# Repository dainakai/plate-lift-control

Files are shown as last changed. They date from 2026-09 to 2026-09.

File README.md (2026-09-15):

# plate-lift-control

Pololu Tic T825で校正用ガラスプレートを上げ下げします。
設定済みの68 mmストロークの装置向けです。

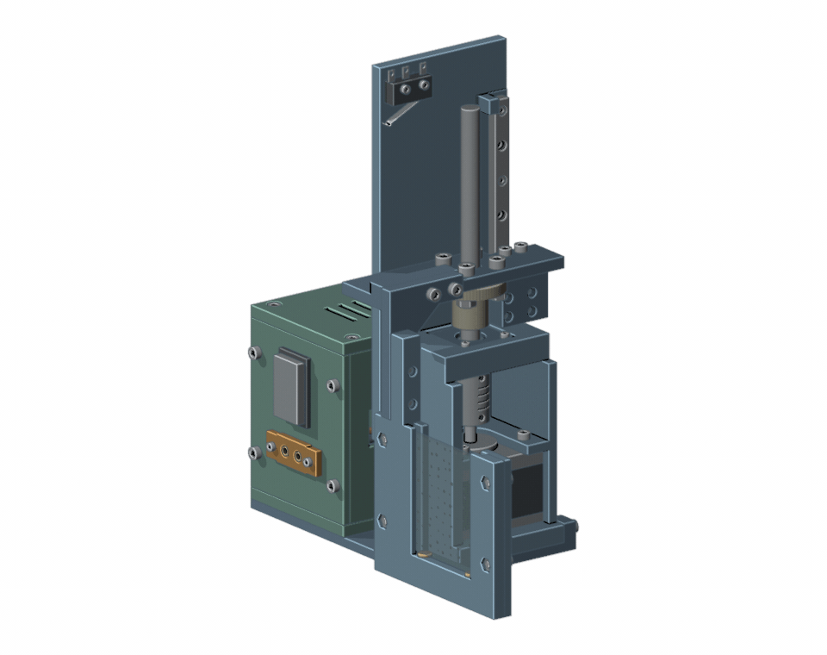
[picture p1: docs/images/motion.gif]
ガラスプレートが68 mm上下する3Dアセンブリの動作イメージ


購入部品を含む3Dモデルの動作イメージです（実機の撮影映像ではありません）。

**[組立・取扱説明書（PDF）](docs/assembly-manual.pdf)** · [購入部材一覧](hardware/bom.md) · **[印刷用STL一式（ZIP）](hardware/print-parts.zip)**

## クイックスタート

### 1. Ticソフトとuvを入れる

すでに入っているものはスキップしてください。

**Mac**

[Pololu公式のTic Software for macOS](https://www.pololu.com/docs/0J71/3.3)をインストールします。
続いてターミナルでuvを入れます。

```bash
curl -LsSf https://astral.sh/uv/install.sh | sh
```

**Windows**

[Pololu公式のTic Software and Drivers for Windows](https://www.pololu.com/docs/0J71/3.1)をインストールします。
続いてPowerShellでuvを入れます。

```powershell
winget install --id=astral-sh.uv -e
```

`winget` がない場合の方法は [uv公式のインストール手順](https://docs.astral.sh/uv/getting-started/installation/)にあります。
インストール後はターミナルまたはPowerShellを開き直してください。

### 2. ダウンロードして準備する

[ZIPをダウンロード](https://github.com/dainakai/plate-lift-control/archive/refs/heads/main.zip)して展開し、`plate-lift-control-main` フォルダを「ダウンロード」に置きます。

Mac：

```bash
cd ~/Downloads/plate-lift-control-main
uv sync
```

Windows：

```powershell
cd "$env:USERPROFILE\Downloads\plate-lift-control-main"
uv sync
```

Pythonとライブラリはuvが準備します。初回はインターネット接続が必要です。

### 3. 上げる／下げる

装置をパソコンへUSB接続し、モーター用のDC電源を接続します。
**DC電源は24 V以下に設定してください。直流安定化電源の最大電圧が21.2 VでもOKです。**
Tic Control Centerが起動中なら閉じてください（[Windowsでは同時にUSB接続できません](https://www.pololu.com/docs/0J71/4.4)）。
以下はMacとWindowsで共通です。必要なほうを実行します。

上げる：

```text
uv run platectl up
```

下げる：

```text
uv run platectl down
```

**普段の操作で、Tic Control Centerを開いてApply settingsを行う必要はありません。**
Ticに保存済みの設定を使います。位置が不明な場合は、指定した側の端を自動で探して停止します。

## その他の操作

| 目的 | コマンド |
| --- | --- |
| 状態を見る | `uv run platectl status` |
| 下端の原点復帰をやり直す | `uv run platectl home` |
| 下げて片付ける | `uv run platectl shutdown` |
| JSONで状態を読む | `uv run platectl status --json` |

通常移動の速度は `150000000`（約14.06 mm/s）です。

## 実験に組み込む

[撮影サンプル](examples/capture_sequence.py)は「上げて校正 → 下げて撮影 → 下端で終了」の流れです。
`capture_calibration()` と `capture_sample()` にカメラの取得処理を入れて使います。
[実行方法とオプション](docs/reference.md#実験スクリプトから使う)

## 必要なときに読む

- [組立・取扱説明書（PDF）](docs/assembly-manual.pdf)／[編集用PowerPoint](docs/assembly-manual.pptx) — 最終更新日：2026年9月15日
- [購入部材一覧](hardware/bom.md)／[CSV](hardware/bom.csv)
- [印刷用STL一式（14部品・ZIP）](hardware/print-parts.zip)／[個別STL](hardware/stl/)／[印刷方法](hardware/printing.md)
- [はめ合い確認用の試験片（ZIP）](hardware/fit-coupons.zip)
- [操作、実験連携、更新の詳細](docs/reference.md)
- [困ったとき](docs/troubleshooting.md)
- [Ticを交換または初期化したときの設定](docs/tic-setup.md)
- [検証範囲](docs/validation.md)／[変更履歴](CHANGELOG.md)／[MIT License](LICENSE)

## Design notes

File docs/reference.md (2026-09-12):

# 操作と実験連携の詳細

[クイックスタート](../README.md#クイックスタート)の補足です。

## 原点復帰と終了

`up` と `down` は、位置が不明なら指定した側のリミットまで原点復帰して停止します。
既知の端からは終点の約2 mm手前まで通常速度で進み、残りを原点復帰の速度で探します。
停止後はモーターを無励磁にします。
スイッチを離すまで少し戻るため、終了時の `limit: none` は正常な場合があります。

`home` は記録済みの位置にかかわらず、下端の原点復帰をやり直します。
手回しや公式アプリで位置を変えた後など、位置の記録を取り直すときに使います。
`up` で上げた位置は、コマンド終了後もそのままです。

片付けるときは `shutdown` を実行し、`position: DOWN`、`motor: de-energized`、`fault: none`、`safe_to_unplug: true` を確認してから主電源とUSBを外します。
`shutdown` は下へ移動する終了処理です。
異常時は装置の主電源を切ってください。

## ストロークと複数台の指定

この公開版の既定値は **68 mm** です。
以前の配布ZIPと異なり、現在のR10/R11装置で毎回 `--travel-mm 68` を付ける必要はありません。
明示的に付けても同じ動作です。

旧50 mmストロークの装置では、すべての操作に `--travel-mm 50` を付けます。
このオプションは取り付け済み機構のストロークを指定するもので、任意の高さへ止めるためのものではありません。

```text
uv run platectl home --travel-mm 50
```

Ticが複数ある場合は、`ticcmd --list` に表示された番号を毎回 `--serial` に指定します。
次の番号は例なので実際の番号へ置き換えてください。

```text
uv run platectl status --serial 01234567
```

`ticcmd` が標準の検索パスにない場合は、`--ticcmd` に実行ファイルのフルパスを指定できます。
パスに空白がある場合は、全体をダブルクォートで囲みます。

## 実験スクリプトから使う

### 撮影シーケンスのサンプル

[examples/capture_sequence.py](../examples/capture_sequence.py) は、次の順序を実装したサンプルです。

1. 下端へ原点復帰する。
2. 上げて停止を確認し、校正画像の取得処理を呼ぶ。
3. 下げて停止を確認し、試料画像の取得処理を呼ぶ。
4. 通常終了時は下端で無励磁になっていることを確認する。

まず、USBを使わない模擬動作を試せます。

```text
uv run python examples/capture_sequence.py --cycles 2
```

既定は `mock` なので実機は動きません。
一時フォルダに模擬動作の状態を置き、実機の位置記録と分けています。
`UP / calibration capture goes here`、`DOWN / sample capture goes here`、最後に `finished: DOWN / motor off` が表示されます。

実機の上下操作を確認できたら、明示的に `--backend ticcmd` を指定します。

```text
uv run python examples/capture_sequence.py --backend ticcmd --cycles 1 --settle-seconds 0.5
```

**このコマンドは実機を動かします。撮影そのものはまだ行いません。**
ファイル内の `capture_calibration()` と `capture_sample()` を、使用するカメラの取得処理に置き換えてください。
`--settle-seconds` は停止後から撮影処理を呼ぶまでの待ち時間です。
必要な待ち時間は撮影画像で確認して調整します。
`--serial`、`--ticcmd`、`--travel-mm` も指定できます。

サンプルは、シーケンス全体で `platectl` と共通のロックを保持します。
別の `platectl` を同時に実行すると終了コード5で拒否されます。
撮影処理だけが失敗した場合は下端への終了処理を行いますが、移動異常、USB通信エラー、`Ctrl+C` のあとには自動で再移動しません。

### 別のプログラムからコマンドを呼ぶ場合

`platectl` は動作が終わるまで戻らない同期コマンドです。
`--json` を付けると、結果をプログラムから読めます。

| JSONの項目 | 意味 |
| --- | --- |
| `ok` | コマンド処理が例外なく完了したか。`status` の `ok: true` だけでは装置の異常なしを意味しません。 |
| `position` | `UP`、`DOWN`、`UNKNOWN` |
| `fault` | 現在の異常一覧。空の配列なら検出中の異常はありません。 |
| `motor_energized` | モーターが励磁中か |
| `safe_to_image` | 既知の端で停止し、無励磁で、異常が検出されていないか |
| `safe_to_unplug` | 上記の条件を満たし、下端にいるか |

撮影に進むときは終了コード0、期待する `position`、`safe_to_image: true` を確認します。
これらのフラグはTicの情報と原点復帰の記録に基づく判断です。
実際のガラス保持力や振動を測定するセンサーではありません。

| 終了コード | 意味 |
| --- | --- |
| 0 | コマンド完了 |
| 2 | 引数の誤り、ticcmdがない、USB通信エラーなど |
| 3 | リミットやTicの異常 |
| 4 | 移動または原点復帰のタイムアウト |
| 5 | 別の操作が実行中 |

`up` と `down` の途中では、1秒の通信タイムアウトを更新し続けます。
移動の期限は68 mm装置で20秒、50 mm装置で10秒です。
移動中の例外や中断では無励磁化を試み、位置の記録を無効にします。

## 更新する

ZIPを使う場合は、新しいZIPを別のフォルダへ展開して `uv sync` を実行します。
自分で編集した撮影処理とTicの設定バックアップは、更新前に保存してください。
アプリの位置記録はOSのユーザー用データ領域にあり、ソースコードのフォルダとは別です。
更新後は `home` から始めます。

Gitを使う場合は、次の方法でも導入できます。

```text
git clone https://github.com/dainakai/plate-lift-control.git
cd plate-lift-control
uv sync
```

以降は、変更を保存したうえで `git pull --ff-only` と `uv sync` を実行します。

## 開発とテスト

```text
uv sync --locked
uv run --locked pytest
uv run --locked ruff check .
```

テストはTicの代替バックエンドを使い、接続された実機へコマンドを送りません。
GitHub ActionsでもmacOS、Windows、Linuxで同じテストを実行します。
CADソフトは不要です。
変更点は [CHANGELOG.md](../CHANGELOG.md)、検証の範囲は [docs/validation.md](validation.md) に記載します。

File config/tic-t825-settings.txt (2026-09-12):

product: T825
control_mode: serial
never_sleep: false
disable_safe_start: false
ignore_err_line_high: false
auto_clear_driver_error: true
soft_error_response: deenergize
soft_error_position: 0
serial_baud_rate: 9600
serial_device_number: 14
serial_alt_device_number: 0
serial_enable_alt_device_number: false
serial_14bit_device_number: false
command_timeout: 1000
serial_crc_for_commands: false
serial_crc_for_responses: false
serial_7bit_responses: false
serial_response_delay: 0
vin_calibration: 0
input_averaging_enabled: true
input_hysteresis: 0
input_scaling_degree: linear
input_invert: false
input_min: 0
input_neutral_min: 2015
input_neutral_max: 2080
input_max: 4095
output_min: -200
output_max: 200
encoder_prescaler: 1
encoder_postscaler: 1
encoder_unlimited: false
scl_config: limit_switch_reverse pullup active_high
sda_config: limit_switch_forward pullup active_high
tx_config: default
rx_config: default
rc_config: default
current_limit: 800
current_limit_during_error: -1
step_mode: 8
decay_mode: mixed
max_speed: 150000000
starting_speed: 0
max_accel: 3333333
max_decel: 3333333
auto_homing: false
auto_homing_forward: false
homing_speed_towards: 64000000
homing_speed_away: 16000000
invert_motor_direction: false

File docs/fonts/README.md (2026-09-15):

# BIZ UDPゴシック

取扱説明スライドとPDFの日本語本文に、Google Fonts版のBIZ UDPゴシックを使う。

- `BIZUDPGothic-Regular.ttf`: 標準。
- `BIZUDPGothic-Bold.ttf`: 太字。
- `OFL-BIZUDPGothic.txt`: SIL Open Font License 1.1。

配布元は[Google FontsのBIZ UDPGothicディレクトリ](https://github.com/google/fonts/tree/main/ofl/bizudpgothic)である。
Mac・WindowsでPPTXを編集する場合は、標準・太字の2個のTTFを先にインストールする。
PDFには書体が埋め込まれているため、閲覧側でのインストールは不要である。

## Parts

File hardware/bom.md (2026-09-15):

# 購入部材一覧

数は装置1台に使う数です。袋やセットの入数とは異なります。
購入先は使用部品の照合用です。同じ型番でも仕様やセット内容を確認してください。

**固定ねじ57本・六角ナット24個・M3インサート26個。** USLL6本体のねじ3本、主電源スイッチとヒューズホルダーの付属ナットは別扱いです。USLL6を固定するM3ナット3個は、六角ナット24個の内数です。

[CSVでダウンロード](bom.csv) ／ [組立・取扱説明書](../docs/assembly-manual.pdf) ／ [印刷用STL一式](print-parts.zip)

## 機構

| 型番・仕様 | 部品名 | 必要数 | 取り付け場所・用途 |
| --- | --- | ---: | --- |
| [C-42STM01](https://jp.misumi-ec.com/vona2/detail/110310526769/?HissuCode=C-42STM01) | 42 mm角ステッピングモーター | 1 | 駆動フレームのU字開口から入れ、M3×8で4点固定 |
| [MTSRA8-120-S20-Q6](https://jp.misumi-ec.com/vona2/detail/110302642010/?HissuCode=MTSRA8-120-S20-Q6) | 送りねじ | 1 | 軸端φ6×20、ねじ部100、全長120 mm。軸受と黄銅ナットを通す |
| [MTSFR8](https://jp.misumi-ec.com/vona2/detail/110302641220/?HissuCode=MTSFR8) | 黄銅フランジナット | 1 | 黄銅ナット取付板の下面。M4×14とM4ナットで4点固定 |
| [SSEB8-100](https://jp.misumi-ec.com/vona2/detail/110302586530/?HissuCode=SSEB8-100) | リニアガイド（レール＋ブロック） | 1組 | レールはフレームへM2×12で4点、ブロックは取付板へM2×6で4点固定 |
| [CPL16-5-6](https://jp.misumi-ec.com/vona2/detail/110300126030/?HissuCode=CPL16-5-6) | カップリング | 1 | モーターのφ5軸と送りねじのφ6軸端を接続 |
| [696ZZ](https://jp.misumi-ec.com/vona2/detail/221301228090/?HissuCode=696ZZ) | 軸受（内径6×外径15×幅5 mm） | 1 | 駆動フレームの軸受座。上下に精密シムを入れ、蓋で押さえる |
| [PSCCJ6-5](https://jp.misumi-ec.com/vona2/detail/110302636320/?HissuCode=PSCCJ6-5) | セットカラー | 1 | 下シムの下で送りねじに固定 |
| [CIMR6-12-0.5](https://jp.misumi-ec.com/vona2/detail/110302677870/?HissuCode=CIMR6-12-0.5) | 精密シム（6×12×0.5 mm） | 2 | 軸受の上下へ各1枚。普通の座金へ置き換えない |
| [USLL6](https://jp.misumi-ec.com/vona2/detail/110302358850/?HissuCode=USLL6) | ウレタン先端の支持ねじ | 3 | ガラスホルダーへ底2本・横1本。M3ナットで固定 |
| 50×50×2.3 mm | ランダムドットガラス | 1 | ホルダーの溝へ挿入。溝幅2.9 mm、支持ねじで3点支持 |

## 検出・制御

| 型番・仕様 | 部品名 | 必要数 | 取り付け場所・用途 |
| --- | --- | ---: | --- |
| [SS-01GL13-E](https://jp.misumi-ec.com/vona2/detail/221000559138/?HissuCode=SS-01GL13-E) | OMRONリミットスイッチ | 2 | フレームの上下へ各1個。COM→GND、下NC→SCL、上NC→SDA |
| [Pololu 3130 / Tic T825](https://www.switch-science.com/products/3398) | USBモーター制御基板（端子実装済み） | 1 | 電子箱の底板へM2×6で2点固定 |
| 2.54 mm・1ピン・メス端子付き | 信号用リード線 | 4 | TicのSCL・SDA・信号GNDと、上下スイッチを接続。長さは現物で決める |

## 電装

| 型番・仕様 | 部品名 | 必要数 | 取り付け場所・用途 |
| --- | --- | ---: | --- |
| [XT60E-F](https://www.amazon.co.jp/dp/B0CQK1P1DP) | リード線付きパネル用XT60メス | 1 | 電源側板の下側。M2×8とM2ナット各2で固定 |
| [エーモン3214](https://www.amazon.co.jp/dp/B075SW22KP) | 主電源スイッチ（非照光） | 1 | 電源側板の上側。付属ナットで固定 |
| [OHM KIT-NR312](https://www.amazon.co.jp/dp/B0DSKS32YZ) | パネル用ヒューズホルダー | 1 | ヒューズ側板のφ13 mm穴。付属ナットで固定 |
| [5.2×20 mm・2 A](https://www.amazon.co.jp/dp/B086Z12VJF) | ガラス管ヒューズ | 1 | KIT-NR312内。エーモン3665セットの2 Aを使用 |
| [WAGO 221-412 / WFR-2BP](https://www.amazon.co.jp/dp/B01E577SMQ) | 2口レバー式中継コネクタ | 2 | 正極用と0 V用に各1個。専用の印刷台は使わない |
| [エーモン3311・250型](https://www.amazon.co.jp/dp/B086XFD4B8) | メス端子と絶縁スリーブ | 各2 | 3214の2端子へ接続。電線に合う圧着工具で加工 |
| [エーモン4942・0.50 sq](https://www.amazon.co.jp/dp/B07PSL1H4J) | 赤黒ダブルコード | 必要長 | 箱内のDC配線。側板を外す余長を確保して現物で切断 |
| [エーモン1196・φ4 mm](https://www.amazon.co.jp/dp/B001JBYGHC) | 熱収縮チューブ | 必要長 | ヒューズホルダーなどのはんだ端子を1本ずつ絶縁 |
| [U2C-AMB10BK](https://www.amazon.co.jp/dp/B005C8RVFM) | ELECOM USB-A–Micro-Bデータケーブル | 1 | パソコン→Tic。USB-CのみのPCはデータ対応変換アダプターも用意 |
| [XT60オス–4 mmバナナ・30 cm・14 AWG](https://www.amazon.co.jp/dp/B07RBKSFX4) | DC電源ケーブル | 1 | 赤を電源＋、黒を0 Vへ。2本組から1本使用 |
| 24 V以下に設定できるDC電源 | 直流安定化電源 | 1 | 装置のXT60へ接続。使用中の21.2 V出力で動作確認済み |

## 固定具

| 型番・仕様 | 部品名 | 必要数 | 取り付け場所・用途 |
| --- | --- | ---: | --- |
| [M3・外径4.6×長さ5.7 mm](https://www.amazon.co.jp/dp/B0G9L9RT4S) | 熱圧入インサート | 26 | 機構8個、USB側板8個、駆動側板8個、ヒューズ側板2個 |
| [M2×6](https://www.amazon.co.jp/dp/B0GVD68M67) | 六角穴付きねじ（長さは首下） | 6 | ガイドブロック4本、Tic基板2本 |
| [M2×8](https://www.amazon.co.jp/dp/B0GVD68M67) | 六角穴付きねじ（長さは首下） | 2 | XT60フランジ2本 |
| [M2×12](https://www.amazon.co.jp/dp/B0GVD68M67) | 六角穴付きねじ（長さは首下） | 7 | レール4本、軸受押さえ3本 |
| [M2×16](https://www.amazon.co.jp/dp/B0GVD68M67) | 六角穴付きねじ（長さは首下） | 4 | 上下リミット各2本 |
| [M3×8](https://www.amazon.co.jp/dp/B0GVD68M67) | 六角穴付きねじ（長さは首下） | 24 | モーター4本、ホルダー前枠4本、電子箱16本 |
| [M3×12](https://www.amazon.co.jp/dp/B0GVD68M67) | 六角穴付きねじ（長さは首下） | 10 | ベース接続4本、キャリア接続4本、ホルダー接続2本 |
| [M4×14](https://www.amazon.co.jp/dp/B0GVD68M67) | 六角穴付きねじ（長さは首下） | 4 | 黄銅フランジナット4本 |
| [M2・対辺4×厚さ1.6 mm](https://jp.misumi-ec.com/vona2/detail/110500137250/?HissuCode=NATTO-2-4-1.6) | 六角ナット | 13 | レール4個、軸受押さえ3個、リミット4個、XT60用2個 |
| [M3](https://www.amazon.co.jp/dp/B0GVD68M67) | 六角ナット | 7 | ホルダー前枠4個、USLL6用3個 |
| [M4](https://www.amazon.co.jp/dp/B0GVD68M67) | 六角ナット | 4 | 黄銅フランジナット用4個 |

## 消耗品

| 型番・仕様 | 部品名 | 必要数 | 取り付け場所・用途 |
| --- | --- | ---: | --- |
| PLAまたは採用した樹脂 | 3Dプリンター用フィラメント | 必要量 | 試験片と本体を同じ材料・造形条件で印刷 |
| 小型結束バンド・配線ラベル | 配線保持・識別用品 | 必要数 | 線束を保持。WAGOのレバーを押さえない |

## 用意する工具

六角レンチ（M2/M3/M4ねじ用）、小型スパナ、はんだごて・インサート用こて先、圧着工具、ワイヤーストリッパー、テスター、ノギスを使います。
M2ねじとナットは狭い場所へ入れるため、ピンセットもあると作業できます。

[READMEへ戻る](../README.md)

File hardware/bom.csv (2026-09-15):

分類 | 型番・仕様 | 部品名 | 装置1台の必要数 | 取り付け場所・用途 | 購入先・製品ページ
機構 | C-42STM01 | 42 mm角ステッピングモーター | 1 | 駆動フレームのU字開口から入れ、M3×8で4点固定 | https://jp.misumi-ec.com/vona2/detail/110310526769/?HissuCode=C-42STM01
機構 | MTSRA8-120-S20-Q6 | 送りねじ | 1 | 軸端φ6×20、ねじ部100、全長120 mm。軸受と黄銅ナットを通す | https://jp.misumi-ec.com/vona2/detail/110302642010/?HissuCode=MTSRA8-120-S20-Q6
機構 | MTSFR8 | 黄銅フランジナット | 1 | 黄銅ナット取付板の下面。M4×14とM4ナットで4点固定 | https://jp.misumi-ec.com/vona2/detail/110302641220/?HissuCode=MTSFR8
機構 | SSEB8-100 | リニアガイド（レール＋ブロック） | 1組 | レールはフレームへM2×12で4点、ブロックは取付板へM2×6で4点固定 | https://jp.misumi-ec.com/vona2/detail/110302586530/?HissuCode=SSEB8-100
機構 | CPL16-5-6 | カップリング | 1 | モーターのφ5軸と送りねじのφ6軸端を接続 | https://jp.misumi-ec.com/vona2/detail/110300126030/?HissuCode=CPL16-5-6
機構 | 696ZZ | 軸受（内径6×外径15×幅5 mm） | 1 | 駆動フレームの軸受座。上下に精密シムを入れ、蓋で押さえる | https://jp.misumi-ec.com/vona2/detail/221301228090/?HissuCode=696ZZ
機構 | PSCCJ6-5 | セットカラー | 1 | 下シムの下で送りねじに固定 | https://jp.misumi-ec.com/vona2/detail/110302636320/?HissuCode=PSCCJ6-5
機構 | CIMR6-12-0.5 | 精密シム（6×12×0.5 mm） | 2 | 軸受の上下へ各1枚。普通の座金へ置き換えない | https://jp.misumi-ec.com/vona2/detail/110302677870/?HissuCode=CIMR6-12-0.5
機構 | USLL6 | ウレタン先端の支持ねじ | 3 | ガラスホルダーへ底2本・横1本。M3ナットで固定 | https://jp.misumi-ec.com/vona2/detail/110302358850/?HissuCode=USLL6
機構 | 50×50×2.3 mm | ランダムドットガラス | 1 | ホルダーの溝へ挿入。溝幅2.9 mm、支持ねじで3点支持
検出・制御 | SS-01GL13-E | OMRONリミットスイッチ | 2 | フレームの上下へ各1個。COM→GND、下NC→SCL、上NC→SDA | https://jp.misumi-ec.com/vona2/detail/221000559138/?HissuCode=SS-01GL13-E
検出・制御 | Pololu 3130 / Tic T825 | USBモーター制御基板（端子実装済み） | 1 | 電子箱の底板へM2×6で2点固定 | https://www.switch-science.com/products/3398
検出・制御 | 2.54 mm・1ピン・メス端子付き | 信号用リード線 | 4 | TicのSCL・SDA・信号GNDと、上下スイッチを接続。長さは現物で決める
電装 | XT60E-F | リード線付きパネル用XT60メス | 1 | 電源側板の下側。M2×8とM2ナット各2で固定 | https://www.amazon.co.jp/dp/B0CQK1P1DP
電装 | エーモン3214 | 主電源スイッチ（非照光） | 1 | 電源側板の上側。付属ナットで固定 | https://www.amazon.co.jp/dp/B075SW22KP
電装 | OHM KIT-NR312 | パネル用ヒューズホルダー | 1 | ヒューズ側板のφ13 mm穴。付属ナットで固定 | https://www.amazon.co.jp/dp/B0DSKS32YZ
電装 | 5.2×20 mm・2 A | ガラス管ヒューズ | 1 | KIT-NR312内。エーモン3665セットの2 Aを使用 | https://www.amazon.co.jp/dp/B086Z12VJF
電装 | WAGO 221-412 / WFR-2BP | 2口レバー式中継コネクタ | 2 | 正極用と0 V用に各1個。専用の印刷台は使わない | https://www.amazon.co.jp/dp/B01E577SMQ
電装 | エーモン3311・250型 | メス端子と絶縁スリーブ | 各2 | 3214の2端子へ接続。電線に合う圧着工具で加工 | https://www.amazon.co.jp/dp/B086XFD4B8
電装 | エーモン4942・0.50 sq | 赤黒ダブルコード | 必要長 | 箱内のDC配線。側板を外す余長を確保して現物で切断 | https://www.amazon.co.jp/dp/B07PSL1H4J
電装 | エーモン1196・φ4 mm | 熱収縮チューブ | 必要長 | ヒューズホルダーなどのはんだ端子を1本ずつ絶縁 | https://www.amazon.co.jp/dp/B001JBYGHC
電装 | U2C-AMB10BK | ELECOM USB-A–Micro-Bデータケーブル | 1 | パソコン→Tic。USB-CのみのPCはデータ対応変換アダプターも用意 | https://www.amazon.co.jp/dp/B005C8RVFM
電装 | XT60オス–4 mmバナナ・30 cm・14 AWG | DC電源ケーブル | 1 | 赤を電源＋、黒を0 Vへ。2本組から1本使用 | https://www.amazon.co.jp/dp/B07RBKSFX4
電装 | 24 V以下に設定できるDC電源 | 直流安定化電源 | 1 | 装置のXT60へ接続。使用中の21.2 V出力で動作確認済み
固定具 | M3・外径4.6×長さ5.7 mm | 熱圧入インサート | 26 | 機構8個、USB側板8個、駆動側板8個、ヒューズ側板2個 | https://www.amazon.co.jp/dp/B0G9L9RT4S
固定具 | M2×6 | 六角穴付きねじ（長さは首下） | 6 | ガイドブロック4本、Tic基板2本 | https://www.amazon.co.jp/dp/B0GVD68M67
固定具 | M2×8 | 六角穴付きねじ（長さは首下） | 2 | XT60フランジ2本 | https://www.amazon.co.jp/dp/B0GVD68M67
固定具 | M2×12 | 六角穴付きねじ（長さは首下） | 7 | レール4本、軸受押さえ3本 | https://www.amazon.co.jp/dp/B0GVD68M67
固定具 | M2×16 | 六角穴付きねじ（長さは首下） | 4 | 上下リミット各2本 | https://www.amazon.co.jp/dp/B0GVD68M67
固定具 | M3×8 | 六角穴付きねじ（長さは首下） | 24 | モーター4本、ホルダー前枠4本、電子箱16本 | https://www.amazon.co.jp/dp/B0GVD68M67
固定具 | M3×12 | 六角穴付きねじ（長さは首下） | 10 | ベース接続4本、キャリア接続4本、ホルダー接続2本 | https://www.amazon.co.jp/dp/B0GVD68M67
固定具 | M4×14 | 六角穴付きねじ（長さは首下） | 4 | 黄銅フランジナット4本 | https://www.amazon.co.jp/dp/B0GVD68M67
固定具 | M2・対辺4×厚さ1.6 mm | 六角ナット | 13 | レール4個、軸受押さえ3個、リミット4個、XT60用2個 | https://jp.misumi-ec.com/vona2/detail/110500137250/?HissuCode=NATTO-2-4-1.6
固定具 | M3 | 六角ナット | 7 | ホルダー前枠4個、USLL6用3個 | https://www.amazon.co.jp/dp/B0GVD68M67
固定具 | M4 | 六角ナット | 4 | 黄銅フランジナット用4個 | https://www.amazon.co.jp/dp/B0GVD68M67
消耗品 | PLAまたは採用した樹脂 | 3Dプリンター用フィラメント | 必要量 | 試験片と本体を同じ材料・造形条件で印刷
消耗品 | 小型結束バンド・配線ラベル | 配線保持・識別用品 | 必要数 | 線束を保持。WAGOのレバーを押さえない

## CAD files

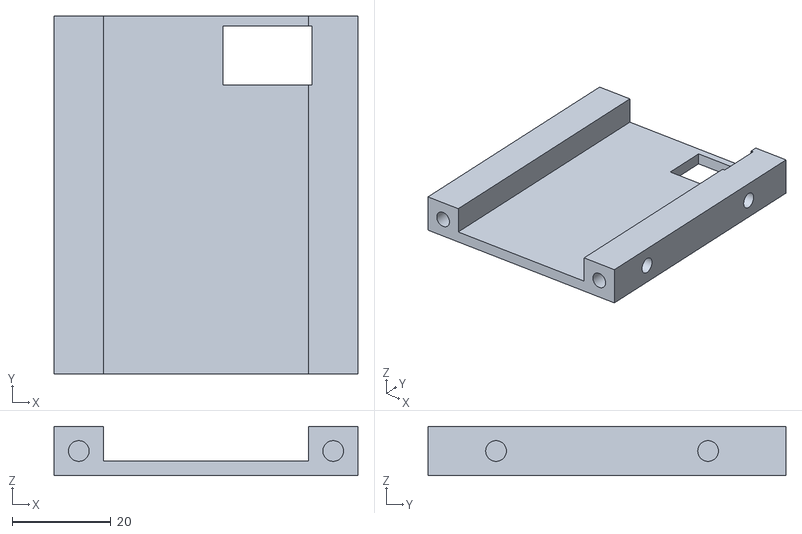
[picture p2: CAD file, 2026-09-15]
hardware/stl/電子箱_USB側板.stl
61.6 x 72.6 x 10.0

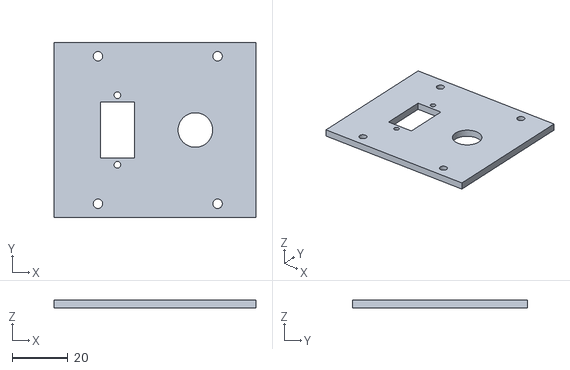
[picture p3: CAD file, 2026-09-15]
hardware/stl/電子箱_電源スイッチ_XT60側板.stl
72.6 x 63.0 x 3.00

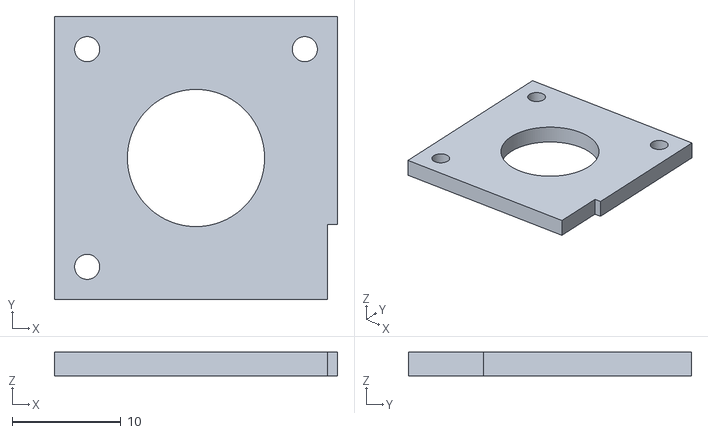
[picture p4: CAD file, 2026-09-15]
hardware/stl/軸受押さえ.stl
26.0 x 26.0 x 2.20

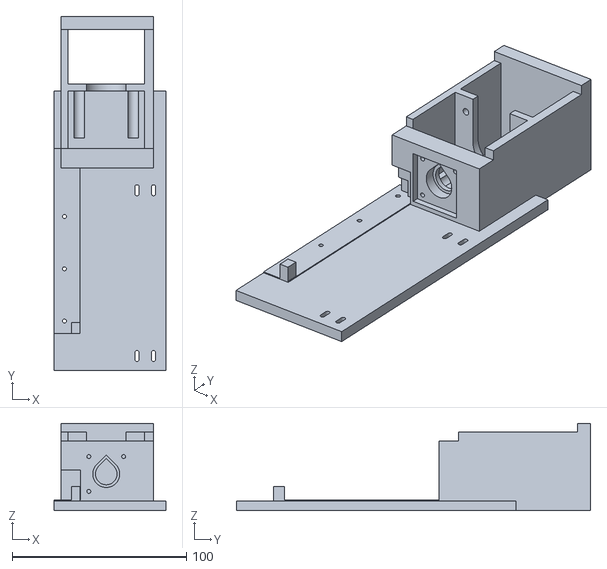
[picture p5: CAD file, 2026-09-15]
hardware/stl/駆動フレーム.stl
64.3 x 203.5 x 50.0

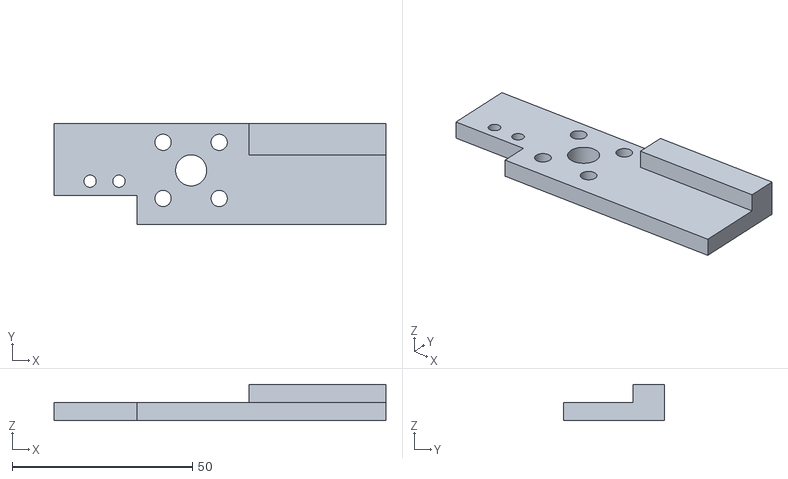
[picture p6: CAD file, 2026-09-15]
hardware/stl/黄銅ナット取付板.stl
92.0 x 28.0 x 10.0

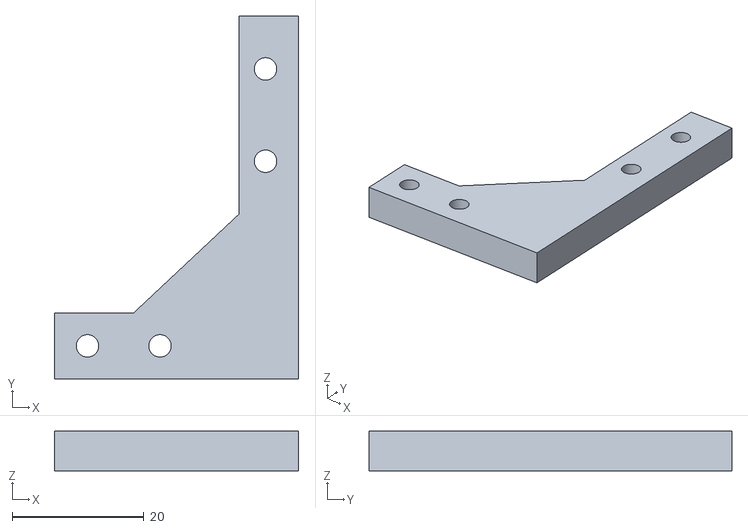
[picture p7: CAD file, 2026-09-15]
hardware/stl/ガラスホルダー接続腕.stl
37.0 x 55.0 x 6.00

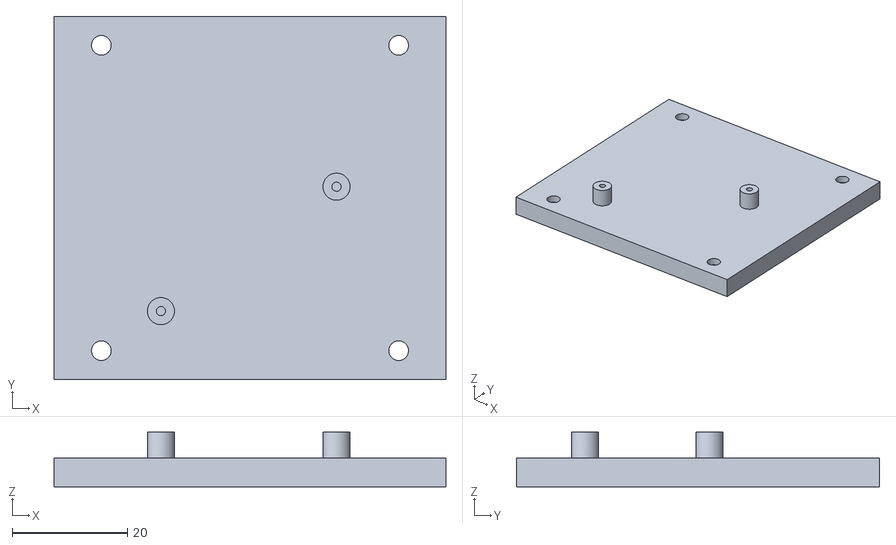
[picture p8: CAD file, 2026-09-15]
hardware/stl/電子箱_底板_Tic取付.stl
68.0 x 63.0 x 9.50

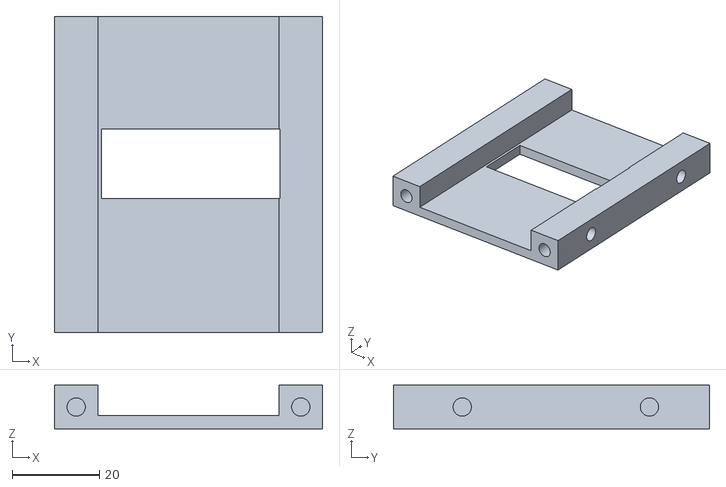
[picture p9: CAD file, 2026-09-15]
hardware/stl/電子箱_駆動側板.stl
61.6 x 72.6 x 10.0

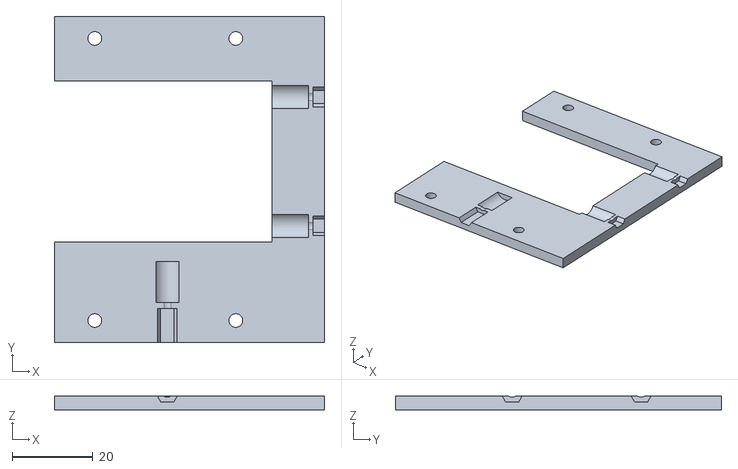
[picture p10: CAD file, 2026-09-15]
hardware/stl/ガラスホルダー前枠.stl
67.0 x 81.0 x 3.40

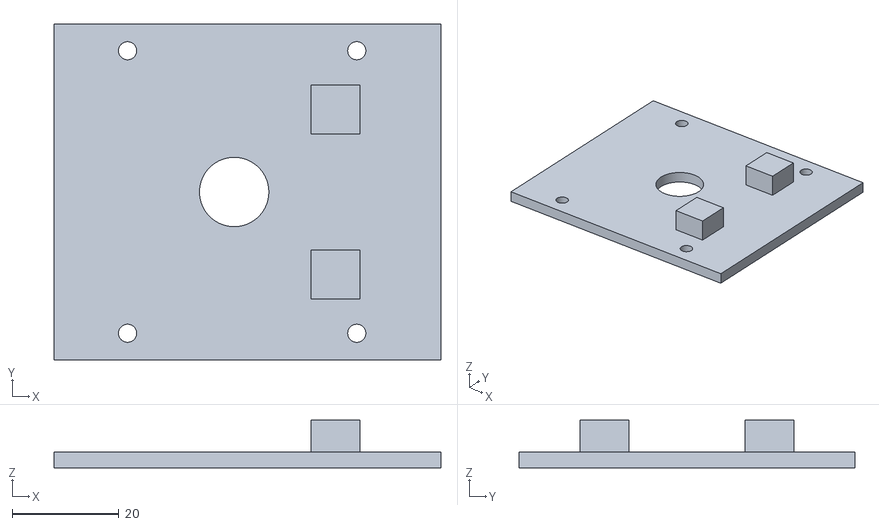
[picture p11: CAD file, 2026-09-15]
hardware/stl/電子箱_ヒューズ側板.stl
72.6 x 63.0 x 9.00

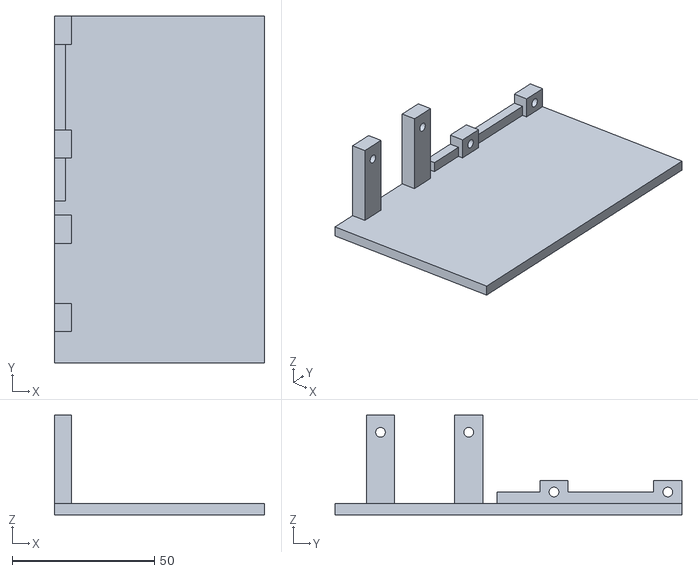
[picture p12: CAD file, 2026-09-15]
hardware/stl/ベース_長手122mm.stl
74.0 x 122.0 x 35.0

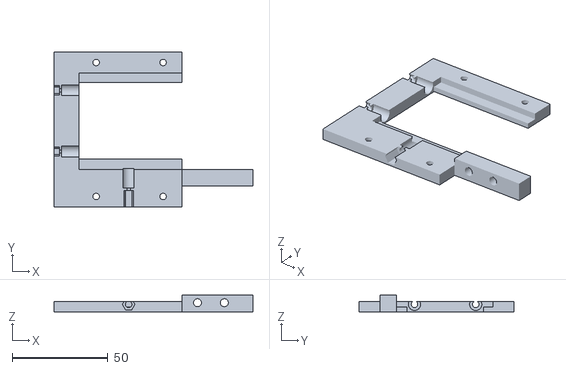
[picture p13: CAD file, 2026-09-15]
hardware/stl/ガラスホルダー本体.stl
104.0 x 81.0 x 8.80

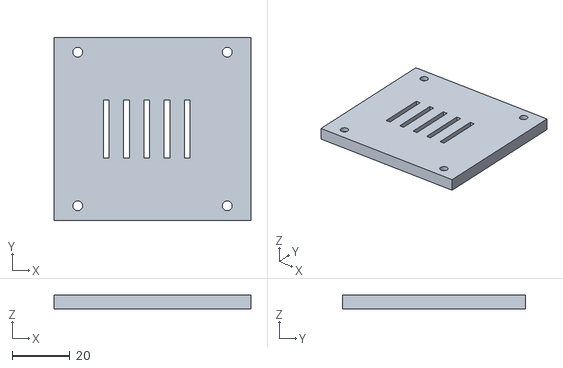
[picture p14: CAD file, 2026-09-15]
hardware/stl/電子箱_天板.stl
68.0 x 63.0 x 5.00

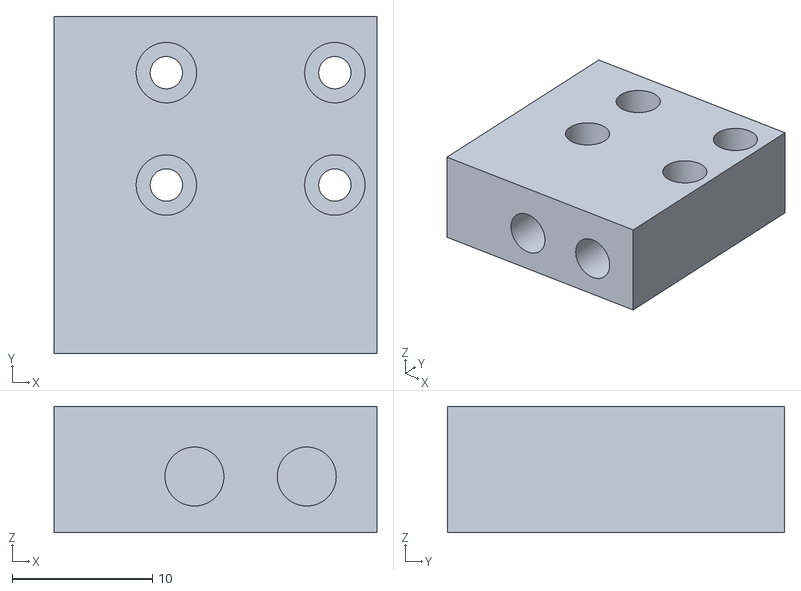
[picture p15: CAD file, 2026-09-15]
hardware/stl/レールブロック取付板.stl
23.0 x 24.0 x 9.00

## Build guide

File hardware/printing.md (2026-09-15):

# 印刷用STL

装置の部品14個を各1個ずつ印刷します。STLの単位はmm、倍率は100%です。
すべて印刷姿勢で書き出しています。Adventurer 5M Proの220×220 mmベッドに各部品が収まります。
一度に全品を同じプレートへ配置する必要はありません。

電子箱の6枚は平らな外面をベッドへ置きます。小さな横穴のブリッジと、駆動フレームの軸受座・蓋の凹みはスライサーで確認してください。
インサートはM3・外径4.6×長さ5.7 mmを26個。圧入する位置と数は説明書の専用ページにあります。

| 部品 | 個数 | 印刷時の外形 X×Y×Z (mm) |
| --- | ---: | --- |
| ベース 長手122mm | 1 | 74 × 122 × 35 |
| 駆動フレーム | 1 | 64.3 × 203.5 × 50 |
| 軸受押さえ | 1 | 26 × 26 × 2.2 |
| 電子箱 底板 Tic取付 | 1 | 68 × 63 × 9.5 |
| 電子箱 天板 | 1 | 68 × 63 × 5 |
| 電子箱 USB側板 | 1 | 61.6 × 72.6 × 10 |
| 電子箱 駆動側板 | 1 | 61.6 × 72.6 × 10 |
| 電子箱 ヒューズ側板 | 1 | 72.6 × 63 × 9 |
| 電子箱 電源スイッチ XT60側板 | 1 | 72.6 × 63 × 3 |
| ガラスホルダー本体 | 1 | 104 × 81 × 8.8 |
| ガラスホルダー前枠 | 1 | 67 × 81 × 3.4 |
| レールブロック取付板 | 1 | 23 × 24 × 9 |
| 黄銅ナット取付板 | 1 | 92 × 28 × 10 |
| ガラスホルダー接続腕 | 1 | 37 × 55 × 6 |

[STL一式をダウンロード](print-parts.zip) ／ [部品を個別に見る](stl/) ／ [組立・取扱説明書](../docs/assembly-manual.pdf)

STLの閉じたメッシュ、各部品が1つの連続した立体であること、印刷範囲を確認済みです。実際のはめ合い・剛性・保持力は印刷物で確認してください。

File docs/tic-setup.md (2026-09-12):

# Ticを交換または初期化したときの設定

通常の利用では、このページの操作は不要です。
Ticを交換、初期化した場合や、モーターと配線を変更した場合に参照してください。
`platectl` は通常移動の速度を設定しますが、リミット、マイクロステップ、モーター電流などはTicに保存済みの値を使います。

## 設定を変更する前に

設定を変更する場合は、先に現在の設定を保存してください。

Tic Control CenterのFileメニューから現在の設定を保存するか、アプリを終了して次を実行します。

```text
ticcmd --get-settings tic-settings-backup.txt
```

このコマンドは設定をPCへ保存するだけで、モーターを動かしません。
保存したファイルは保管してください。

| 設定項目 | このソフトが想定する値 |
| --- | --- |
| Ticの機種 | T825 |
| Control mode | Serial / I²C / USB |
| モーターと送りねじ | 200フルステップ/回転、リード1.5 mm |
| Step mode | 1/8 |
| 正方向 | ガラスが上がる方向 |
| SCL | 下端のReverse limit、プルアップ有効、Active high |
| SDA/AN | 上端のForward limit、プルアップ有効、Active high |
| Command timeout | 有効、1000 ms |
| Soft error response | De-energize |
| Automatic homing | 無効 |
| Homing speed towards | `64000000`（6 mm/s） |
| Homing speed away | `16000000`（1.5 mm/s） |
| Max acceleration / deceleration | `3333333`（約31.25 mm/s²） |

通常移動の最大速度は、`platectl` が移動時に `150000000`（約14.06 mm/s）へ設定します。
原点復帰の速度、モーター電流、マイクロステップ、リミットの割り当てはTic側の設定を使います。
電源装置で観測した約0.27 Aは入力電流です。Ticのモーター各相の電流制限へそのまま転記する値ではありません。

## 設定を適用する

[config/tic-t825-settings.txt](../config/tic-t825-settings.txt) に、この装置用の設定ひな型があります。
機構と配線が上表に一致する場合、Tic Control Centerの **File → Open settings file…** から開き、**Apply settings** で反映します。
ひな型のモーター電流上限は800 mAです。使用するモーターに合わせて確認し、すでに動作確認した電流値や回転方向の変更があれば引き継いでください。
[Pololuの設定ファイル説明](https://www.pololu.com/docs/0J71/5.7)、[モーター設定説明](https://www.pololu.com/docs/0J71/4.3)

リミットスイッチは、下端が **COM→GND、NC→SCL**、上端が **COM→GND、NC→SDA/AN** です。
NO端子は使いません。
モーター用電源を切った状態で、USBから状態を読みながら確認できます。

| スイッチの状態 | Forward limit active | Reverse limit active |
| --- | --- | --- |
| 両方離している | No | No |
| 下端だけ押している | No | Yes |
| 上端だけ押している | Yes | No |

ツメが機構の突き当たりより先にスイッチを押すことと、正方向で上がることも確認してから使います。
[Pololuのリミットスイッチ設定説明](https://www.pololu.com/docs/0J71/4.14)

[クイックスタートへ戻る](../README.md#クイックスタート)

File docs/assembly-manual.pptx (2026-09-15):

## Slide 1

組立・取扱説明書

ガラスプレート昇降装置

最終更新日：2026年9月15日

購入した部品を、
どこへ・どの向きで・
どう固定するか

68 mm昇降・6分割の電子箱
部材・組立・配線・使い方
Adventurer 5M Pro対応

最終更新日：2026年9月15日

01

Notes: ガラスプレート昇降装置
最終更新日：2026年9月15日
https://github.com/dainakai/plate-lift-control
https://www.pololu.com/product/3130/specs
https://www.pololu.com/docs/0J71/4.2
https://www.pololu.com/docs/0J71/4.14
https://www.fa.omron.co.jp/product/item/SS-01GL13-E/

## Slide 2

最初に

この説明書の読み方

図の読み方 | 意味
分解図 | 部品を離した説明図。固定後は合わせ面を密着させる
挿入図 | 挿入前後の図で、部品を入れる方向を確認する
部品名と型番 | 購入部材一覧・部品の袋・STLの名前と照合する
図の向き | モーターのU字開口側を駆動部の正面と呼ぶ
確認欄 | 工程を終える前に、現物で確かめること

寸法の単位はmm。図中の金色は黄銅ナット・インサート、銀色はねじなどの金属部品。

最終更新日：2026年9月15日

02

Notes: この説明書の読み方
寸法の単位はmm。図中の金色は黄銅ナット・インサート、銀色はねじなどの金属部品。
https://github.com/dainakai/plate-lift-control
https://www.pololu.com/product/3130/specs
https://www.pololu.com/docs/0J71/4.2
https://www.pololu.com/docs/0J71/4.14
https://www.fa.omron.co.jp/product/item/SS-01GL13-E/

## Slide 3

装置の全体像

完成時の向きと高さ

DOWN：ガラス下面17 mm

UP：ガラス下面85 mm

実験台の上面から測る。移動量は68 mm。実機ではスイッチの復帰位置で合わせる。

最終更新日：2026年9月15日

03

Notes: 完成時の向きと高さ
実験台の上面から測る。移動量は68 mm。実機ではスイッチの復帰位置で合わせる。
https://github.com/dainakai/plate-lift-control
https://www.pololu.com/product/3130/specs
https://www.pololu.com/docs/0J71/4.2
https://www.pololu.com/docs/0J71/4.14
https://www.fa.omron.co.jp/product/item/SS-01GL13-E/

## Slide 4

作業の道順

どの順番で組むか

工程 | ページ
部品・ねじ・インサートの準備 | p.6–30
モーター・軸受・送りねじ | p.31–39
レール・キャリア・リミット・ホルダー | p.40–55
電子箱と配線 | p.56–81
試験片・印刷・高さ調整 | p.82–93
通電・パソコン準備・使い方・保守 | p.94–110

先にインサートを入れる。軸まわりを組んだ後にキャリアとホルダーを取り付ける。

最終更新日：2026年9月15日

04

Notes: どの順番で組むか
先にインサートを入れる。軸まわりを組んだ後にキャリアとホルダーを取り付ける。
https://github.com/dainakai/plate-lift-control
https://www.pololu.com/product/3130/specs
https://www.pololu.com/docs/0J71/4.2
https://www.pololu.com/docs/0J71/4.14
https://www.fa.omron.co.jp/product/item/SS-01GL13-E/

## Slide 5

装置の全体像

装置の構成と寸法

対象 | 仕様
送りねじ | MTSRA8-120-S20-Q6／移動量68 mm
ベース | 短手74 × 長手122 mm。フレームと電子箱を同じ側から固定
キャリア | レールブロック取付板・黄銅ナット取付板・接続腕の3部品
リミット | 黄銅ナット取付板の上下の面で、スイッチのレバーを押す
電子箱 | 幅68 × 奥行63 × 高さ83 mm。6枚のパネルをねじで組む
印刷部品 | 14部品を各1個。STLは印刷姿勢・mm単位で収録

ガラス50×50×2.3 mm、ホルダー溝2.9 mm。機械ストップとリミットを両方使う。

最終更新日：2026年9月15日

05

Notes: 装置の構成と寸法
ガラス50×50×2.3 mm、ホルダー溝2.9 mm。機械ストップとリミットを両方使う。
https://github.com/dainakai/plate-lift-control
https://www.pololu.com/product/3130/specs
https://www.pololu.com/docs/0J71/4.2
https://www.pololu.com/docs/0J71/4.14
https://www.fa.omron.co.jp/product/item/SS-01GL13-E/

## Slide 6

準備

印刷部品の照合：ベースと駆動部

ベース

74×122 mm
電子箱側の端まで底板がある

駆動フレーム

モーター用U字開口
軸受押さえ用の凹みを備える

軸受押さえ（蓋）

フレームの凹みに収める
M2×12で3点固定

最終更新日：2026年9月15日

06

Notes: 印刷部品の照合：ベースと駆動部
https://github.com/dainakai/plate-lift-control
https://www.pololu.com/product/3130/specs
https://www.pololu.com/docs/0J71/4.2
https://www.pololu.com/docs/0J71/4.14
https://www.fa.omron.co.jp/product/item/SS-01GL13-E/

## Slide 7

準備

印刷部品の照合：電子箱の6枚

底板（Tic取付）

基板用の小さな柱が2本

天板

中央の通気穴・四隅のねじ穴

USB側板

下寄りの18×12 mm開口

駆動側板

中央の41×16 mm配線口

ヒューズ側板

丸穴1個・ベース用受け2個

電源側板（I/Oパネル）

主電源の丸穴・XT60の角穴

最終更新日：2026年9月15日

07

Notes: 印刷部品の照合：電子箱の6枚
https://github.com/dainakai/plate-lift-control
https://www.pololu.com/product/3130/specs
https://www.pololu.com/docs/0J71/4.2
https://www.pololu.com/docs/0J71/4.14
https://www.fa.omron.co.jp/product/item/SS-01GL13-E/

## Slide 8

準備

印刷部品の照合：可動部

レールブロック取付板

M2穴4個
上面：M3インサート2個

黄銅ナット取付板

M4穴4個
側面：M3インサート2個

ガラスホルダー接続腕

厚さ6 mm・2組のM3取付穴

ガラスホルダー本体

ガラス溝2.9 mm
側面：M3インサート2個

ガラスホルダー前枠

本体と合わせてガラスを保持

最終更新日：2026年9月15日

08

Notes: 印刷部品の照合：可動部
https://github.com/dainakai/plate-lift-control
https://www.pololu.com/product/3130/specs
https://www.pololu.com/docs/0J71/4.2
https://www.pololu.com/docs/0J71/4.14
https://www.fa.omron.co.jp/product/item/SS-01GL13-E/

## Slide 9

購入部品の照合

機構部品：回転を上下動へ

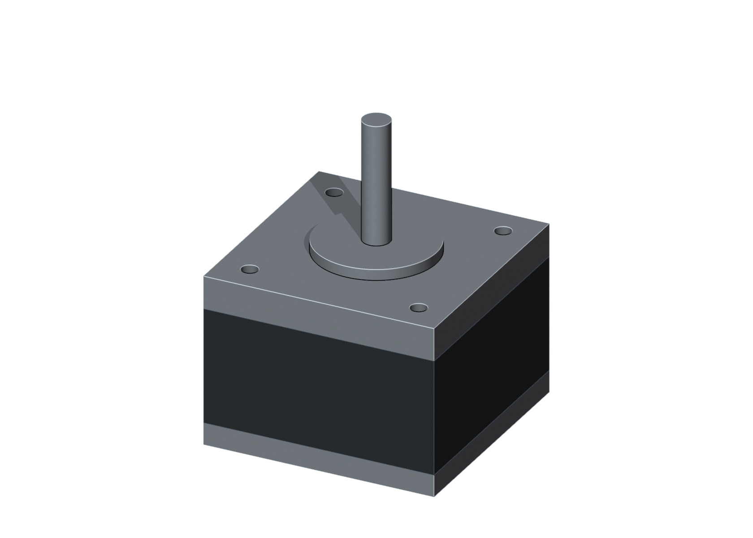
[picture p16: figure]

ステッピングモーター

送りねじ

黄銅フランジナット

C-42STM01

使う数：1

MTSRA8-120-S20-Q6

使う数：1

MTSFR8

使う数：1

単体3Dモデルで部品を照合し、以降の工程で取り付け位置を確認する。

最終更新日：2026年9月15日

09

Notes: 機構部品：回転を上下動へ
https://github.com/dainakai/plate-lift-control
https://www.pololu.com/product/3130/specs
https://www.pololu.com/docs/0J71/4.2
https://www.pololu.com/docs/0J71/4.14
https://www.fa.omron.co.jp/product/item/SS-01GL13-E/

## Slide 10

購入部品の照合

機構部品：軸と直進の案内

リニアガイド（レール＋ブロック）

軸継手（カップリング）

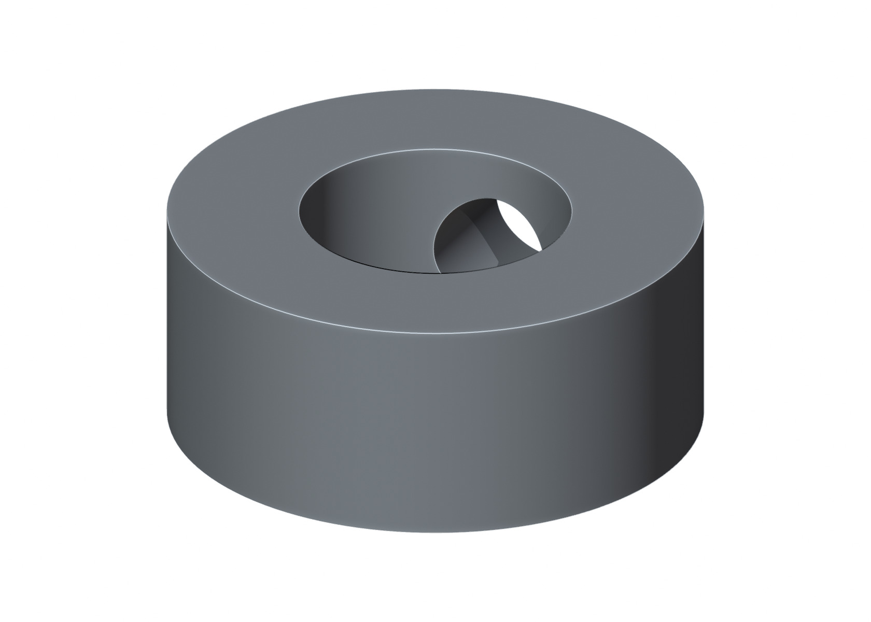
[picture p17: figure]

セットカラー

SSEB8-100

使う数：1組

CPL16-5-6

使う数：1

PSCCJ6-5

使う数：1

単体3Dモデルで部品を照合し、以降の工程で取り付け位置を確認する。

最終更新日：2026年9月15日

10

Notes: 機構部品：軸と直進の案内
https://github.com/dainakai/plate-lift-control
https://www.pololu.com/product/3130/specs
https://www.pololu.com/docs/0J71/4.2
https://www.pololu.com/docs/0J71/4.14
https://www.fa.omron.co.jp/product/item/SS-01GL13-E/

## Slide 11

購入部品の照合

小さな部品も役割を確認

深溝玉軸受

精密シム

ウレタン先端の支持ねじ

696ZZ

使う数：1

CIMR6-12-0.5

使う数：2

USLL6

使う数：3

単体3Dモデルで部品を照合し、以降の工程で取り付け位置を確認する。

最終更新日：2026年9月15日

11

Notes: 小さな部品も役割を確認
https://github.com/dainakai/plate-lift-control
https://www.pololu.com/product/3130/specs
https://www.pololu.com/docs/0J71/4.2
https://www.pololu.com/docs/0J71/4.14
https://www.fa.omron.co.jp/product/item/SS-01GL13-E/

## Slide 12

購入部品の照合

検出・制御・ガラス

リミットスイッチ

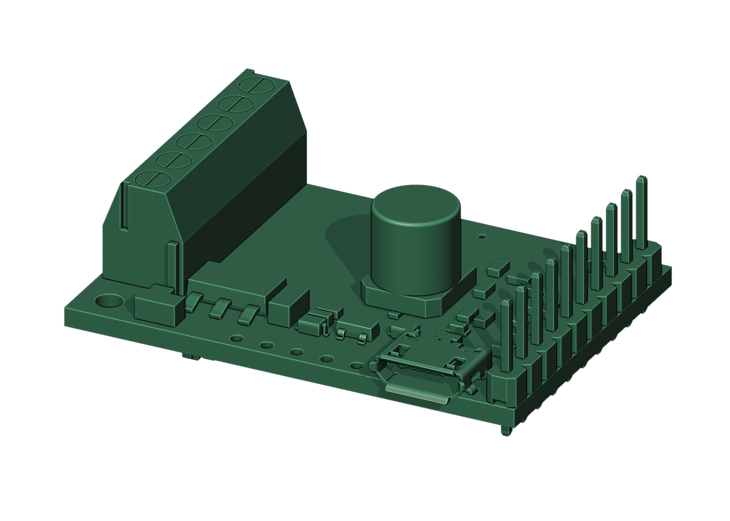
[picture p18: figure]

USBモーター制御基板

ランダムドットガラス

SS-01GL13-E

使う数：2

Pololu 3130 / Tic T825

使う数：1

50×50×2.3 mm

使う数：1

単体3Dモデルで部品を照合し、以降の工程で取り付け位置を確認する。

最終更新日：2026年9月15日

12

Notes: 検出・制御・ガラス
https://github.com/dainakai/plate-lift-control
https://www.pololu.com/product/3130/specs
https://www.pololu.com/docs/0J71/4.2
https://www.pololu.com/docs/0J71/4.14
https://www.fa.omron.co.jp/product/item/SS-01GL13-E/

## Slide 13

購入部品の照合

電源を受ける部品

パネル用XT60メス

XT60–バナナ電源ケーブル

主電源ロッカースイッチ

LINSYRC XT60E-F

使う数：1

Yiqigou B07RBKSFX4

使う数：1本使用（2本組）

エーモン3214

使う数：1

単体3Dモデルで部品を照合し、以降の工程で取り付け位置を確認する。

最終更新日：2026年9月15日

13

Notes: 電源を受ける部品
https://github.com/dainakai/plate-lift-control
https://www.pololu.com/product/3130/specs
https://www.pololu.com/docs/0J71/4.2
https://www.pololu.com/docs/0J71/4.14
https://www.fa.omron.co.jp/product/item/SS-01GL13-E/

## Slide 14

購入部品の照合

ヒューズと電線の中継

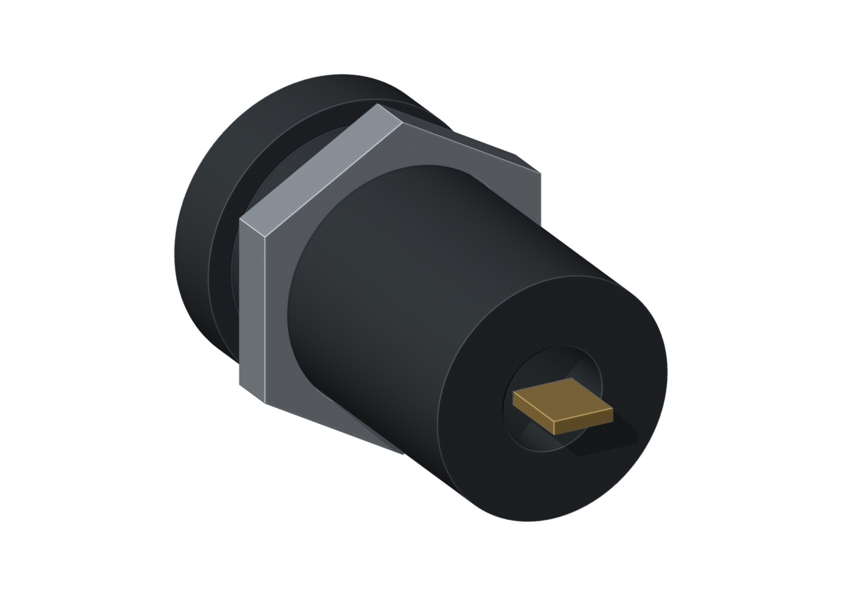
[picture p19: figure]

パネル用ヒューズホルダー

ガラス管ヒューズ 2 A

レバー式中継コネクタ

OHM KIT-NR312

使う数：1

エーモン3665内の2 A

使う数：1

WAGO 221-412 / WFR-2BP

使う数：2

単体3Dモデルで部品を照合し、以降の工程で取り付け位置を確認する。

最終更新日：2026年9月15日

14

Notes: ヒューズと電線の中継
https://github.com/dainakai/plate-lift-control
https://www.pololu.com/product/3130/specs
https://www.pololu.com/docs/0J71/4.2
https://www.pololu.com/docs/0J71/4.14
https://www.fa.omron.co.jp/product/item/SS-01GL13-E/

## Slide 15

購入部品の照合

端末を作る部品

250型メス端子＋スリーブ

熱収縮チューブ

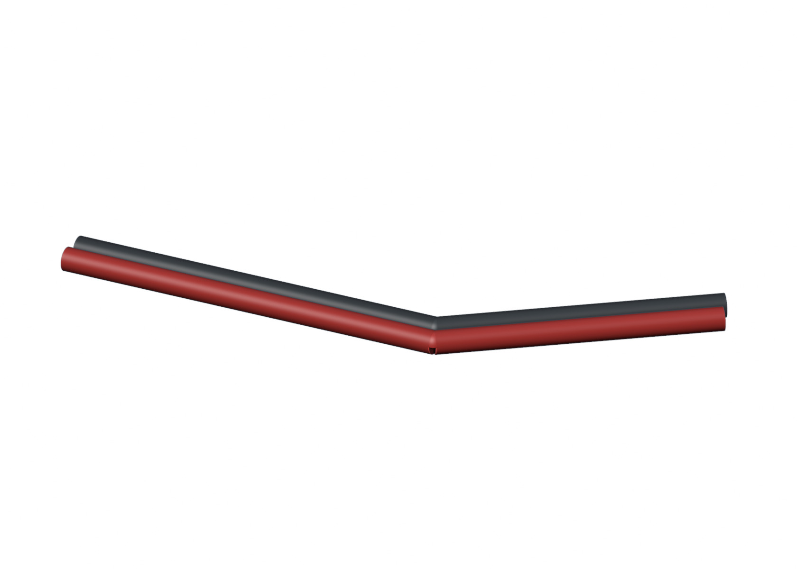
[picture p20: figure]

赤黒ダブルコード 0.50 sq

エーモン3311

使う数：各2

エーモン1196

使う数：必要長に切断

エーモン4942

使う数：必要長に切断

単体3Dモデルで部品を照合し、以降の工程で取り付け位置を確認する。

最終更新日：2026年9月15日

15

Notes: 端末を作る部品
https://github.com/dainakai/plate-lift-control
https://www.pololu.com/product/3130/specs
https://www.pololu.com/docs/0J71/4.2
https://www.pololu.com/docs/0J71/4.14
https://www.fa.omron.co.jp/product/item/SS-01GL13-E/

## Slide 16

購入部品の照合

USB・ナット・インサート

USB-A–Micro-Bケーブル

六角ナット M2

熱圧入インサート M3

ELECOM U2C-AMB10BK

使う数：1

NATTO-2-4-1.6

使う数：13

M3・外径4.6×長さ5.7 mm

使う数：26

単体3Dモデルで部品を照合し、以降の工程で取り付け位置を確認する。

最終更新日：2026年9月15日

16

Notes: USB・ナット・インサート
https://github.com/dainakai/plate-lift-control
https://www.pololu.com/product/3130/specs
https://www.pololu.com/docs/0J71/4.2
https://www.pololu.com/docs/0J71/4.14
https://www.fa.omron.co.jp/product/item/SS-01GL13-E/

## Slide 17

ねじの準備

ねじは「首下の長さ」で選ぶ

01

M2・M3・M4は、ねじ部の太さ。袋を分けて並べる。

×12などの長さは、頭を含めず首下から先端まで測る。

02

03

座金や長いねじを勝手に足さず、次の表の組合せを使う。

確認：頭の形・六角レンチのサイズも現物と合わせる。

六角穴付きねじセット B0GVD68M67

最終更新日：2026年9月15日

17

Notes: ねじは「首下の長さ」で選ぶ
六角穴付きねじセット B0GVD68M67
M2・M3・M4は、ねじ部の太さ。袋を分けて並べる。
×12などの長さは、頭を含めず首下から先端まで測る。
座金や長いねじを勝手に足さず、次の表の組合せを使う。
頭の形・六角レンチのサイズも現物と合わせる。
https://github.com/dainakai/plate-lift-control
https://www.pololu.com/product/3130/specs
https://www.pololu.com/docs/0J71/4.2
https://www.pololu.com/docs/0J71/4.14
https://www.fa.omron.co.jp/product/item/SS-01GL13-E/

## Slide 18

ねじの準備

機構に使うねじ・ナット

固定する場所 | ねじ | ナット
モーターと駆動フレーム | M3×8：4本 | 不要
レールと駆動フレーム | M2×12：4本 | M2：4個
MTSFR8と黄銅ナット取付板 | M4×14：4本 | M4：4個
軸受押さえとフレーム | M2×12：3本 | M2：3個
ブロックとレールブロック取付板 | M2×6：4本 | 不要
上下リミットとフレーム | M2×16：4本 | M2：4個

レール付属M2×6はフレーム固定に使わない。精密シムを普通の座金へ置き換えない。

最終更新日：2026年9月15日

18

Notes: 機構に使うねじ・ナット
レール付属M2×6はフレーム固定に使わない。精密シムを普通の座金へ置き換えない。
https://github.com/dainakai/plate-lift-control
https://www.pololu.com/product/3130/specs
https://www.pololu.com/docs/0J71/4.2
https://www.pololu.com/docs/0J71/4.14
https://www.fa.omron.co.jp/product/item/SS-01GL13-E/

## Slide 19

ねじの準備

キャリア3部品をつなぐねじ

接続する部品 | ねじ | 受ける側
黄銅ナット取付板とレール取付板 | M3×12：2本 | レール取付板の上面インサート
接続腕と黄銅ナット取付板 | M3×12：2本 | 黄銅ナット取付板の側面インサート
接続腕とガラスホルダー | M3×12：2本 | ホルダーの側面インサート
取付板とSSEB8ブロック | M2×6：4本 | ブロックのM2ねじ穴

黄銅ナット取付板 → レール取付板 → ブロック、接続腕 → 黄銅ナット取付板を図で確認する。

最終更新日：2026年9月15日

19

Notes: キャリア3部品をつなぐねじ
黄銅ナット取付板 → レール取付板 → ブロック、接続腕 → 黄銅ナット取付板を図で確認する。
https://github.com/dainakai/plate-lift-control
https://www.pololu.com/product/3130/specs
https://www.pololu.com/docs/0J71/4.2
https://www.pololu.com/docs/0J71/4.14
https://www.fa.omron.co.jp/product/item/SS-01GL13-E/

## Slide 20

ねじの準備

ガラス保持・基板・ベースのねじ

固定する場所 | ねじ | 相手
前枠 → ホルダー本体 | M3×8：4本 | M3ナット：4個
支持ねじ USLL6：3本 | 付属M3ねじ部 | M3ナット：3個
駆動フレーム → ベース | M3×12：2本 | フレームのインサート
電子箱 → ベース | M3×12：2本 | ヒューズ側板のインサート
Tic → 底板 | M2×6：2本 | φ1.6の樹脂下穴
XT60 → 電源側板 | M2×8：2本 | M2ナット：2個

USLL6の支持ねじ3本は購入部品。M3の六角ナットで固定する。

最終更新日：2026年9月15日

20

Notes: ガラス保持・基板・ベースのねじ
USLL6の支持ねじ3本は購入部品。M3の六角ナットで固定する。
https://github.com/dainakai/plate-lift-control
https://www.pololu.com/product/3130/specs
https://www.pololu.com/docs/0J71/4.2
https://www.pololu.com/docs/0J71/4.14
https://www.fa.omron.co.jp/product/item/SS-01GL13-E/

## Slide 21

ねじの準備

電子箱を組むねじは16本

取り付ける板 | ねじ | ねじを受ける側
底板 | M3×8：4本 | USB側板2本＋駆動側板2本
天板 | M3×8：4本 | USB側板2本＋駆動側板2本
ヒューズ側板 | M3×8：4本 | USB側板2本＋駆動側板2本
電源側板（I/Oパネル） | M3×8：4本 | USB側板2本＋駆動側板2本
装置全体の合計 | 固定ねじ57本 | 六角ナット24個・インサート26個

固定ねじの合計にUSLL6の一体ねじは含めない。普通の座金は使わない。

最終更新日：2026年9月15日

21

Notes: 電子箱を組むねじは16本
固定ねじの合計にUSLL6の一体ねじは含めない。普通の座金は使わない。
https://github.com/dainakai/plate-lift-control
https://www.pololu.com/product/3130/specs
https://www.pololu.com/docs/0J71/4.2
https://www.pololu.com/docs/0J71/4.14
https://www.fa.omron.co.jp/product/item/SS-01GL13-E/

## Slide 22

インサートの取り付け

機構のインサート：4部品へ8個

入れる部品 | 穴の場所 | 個数
駆動フレーム | ベースと接する下端側面の2穴 | 2
ガラスホルダー本体 | 高い柱の側面に縦に並ぶ2穴 | 2
レールブロック取付板 | 黄銅ナット取付板を留める上面の2穴 | 2
黄銅ナット取付板 | 接続腕を留める側面の2穴 | 2
機構の小計 | 4部品 | 8

すべてM3、外径4.6 × 長さ5.7 mm。採用した下穴はφ4.2 mm。

最終更新日：2026年9月15日

22

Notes: 機構のインサート：4部品へ8個
すべてM3、外径4.6 × 長さ5.7 mm。採用した下穴はφ4.2 mm。
https://github.com/dainakai/plate-lift-control
https://www.pololu.com/product/3130/specs
https://www.pololu.com/docs/0J71/4.2
https://www.pololu.com/docs/0J71/4.14
https://www.fa.omron.co.jp/product/item/SS-01GL13-E/

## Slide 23

インサートの取り付け

電子箱のインサート：3部品へ18個

入れる部品 | 穴の場所 | 個数
USB側板 | 左右側面4穴、上端2穴、下端2穴 | 8
駆動側板 | 左右側面4穴、上端2穴、下端2穴 | 8
ヒューズ側板 | 外側からベースのねじを受ける2穴 | 2
電子箱の小計 | 3部品 | 18
装置全体 | 機構8個 ＋ 電子箱18個 | 26

底板・天板・電源側板・ベースには入れない。電子箱の下穴は深さ7.3 mm。

最終更新日：2026年9月15日

23

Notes: 電子箱のインサート：3部品へ18個
底板・天板・電源側板・ベースには入れない。電子箱の下穴は深さ7.3 mm。
https://github.com/dainakai/plate-lift-control
https://www.pololu.com/product/3130/specs
https://www.pololu.com/docs/0J71/4.2
https://www.pololu.com/docs/0J71/4.14
https://www.fa.omron.co.jp/product/item/SS-01GL13-E/

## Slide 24

インサートの取り付け

駆動フレーム下端に2個

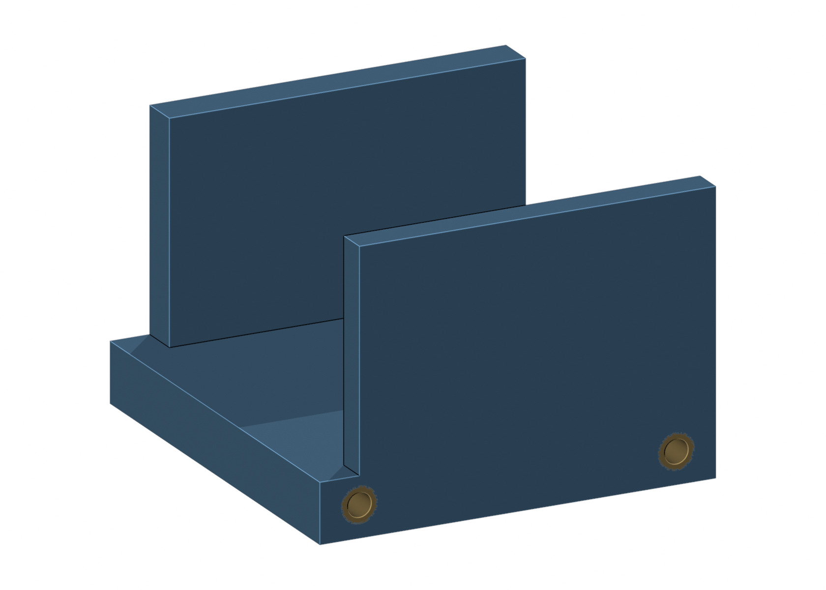
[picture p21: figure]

01

ベースと接する、下端の側面にある2穴を探す。

2穴とも同じ側から圧入し、入口を面とそろえる。

02

03

この面をベースの取付壁へ合わせ、外側からM3×12で固定する。

確認：電子箱の固定ねじも、ベースの同じ側から入る。

駆動フレーム ／ M3インサート ×2

最終更新日：2026年9月15日

24

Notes: 駆動フレーム下端に2個
駆動フレーム ／ M3インサート ×2
ベースと接する、下端の側面にある2穴を探す。
2穴とも同じ側から圧入し、入口を面とそろえる。
この面をベースの取付壁へ合わせ、外側からM3×12で固定する。
電子箱の固定ねじも、ベースの同じ側から入る。
https://github.com/dainakai/plate-lift-control
https://www.pololu.com/product/3130/specs
https://www.pololu.com/docs/0J71/4.2
https://www.pololu.com/docs/0J71/4.14
https://www.fa.omron.co.jp/product/item/SS-01GL13-E/

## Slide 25

インサートの取り付け

キャリアの取付板へ2個ずつ

レールブロック取付板：上から2個

黄銅ナット取付板：側面から2個

追加するインサートは計4個。接続腕には入れない。

最終更新日：2026年9月15日

25

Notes: キャリアの取付板へ2個ずつ
追加するインサートは計4個。接続腕には入れない。
https://github.com/dainakai/plate-lift-control
https://www.pololu.com/product/3130/specs
https://www.pololu.com/docs/0J71/4.2
https://www.pololu.com/docs/0J71/4.14
https://www.fa.omron.co.jp/product/item/SS-01GL13-E/

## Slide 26

インサートの取り付け

USB側板へ8個：向きを変えて確認

上端2個＋片側の側面2個

下端2個＋反対側の側面2個

オレンジの丸が圧入位置。上端・下端は板の端面から、側面は横から入れる。

最終更新日：2026年9月15日

26

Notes: USB側板へ8個：向きを変えて確認
オレンジの丸が圧入位置。上端・下端は板の端面から、側面は横から入れる。
https://github.com/dainakai/plate-lift-control
https://www.pololu.com/product/3130/specs
https://www.pololu.com/docs/0J71/4.2
https://www.pololu.com/docs/0J71/4.14
https://www.fa.omron.co.jp/product/item/SS-01GL13-E/

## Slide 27

インサートの取り付け

駆動側板へ8個：USB側板と同じ配置

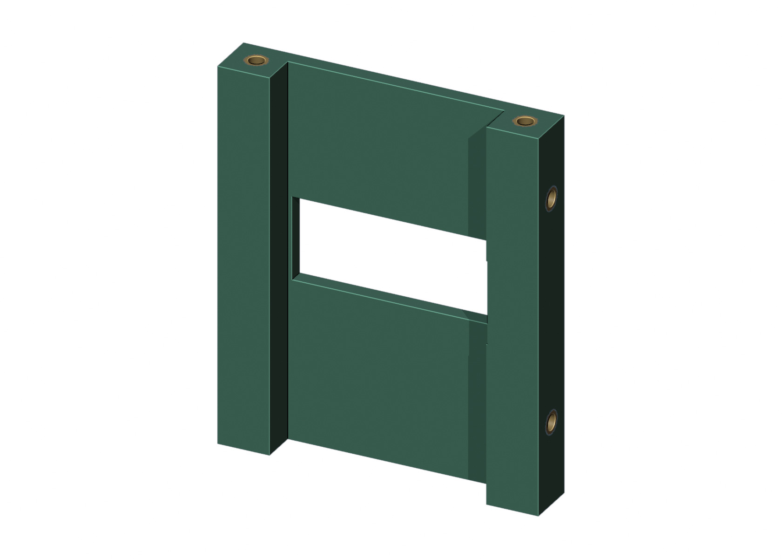
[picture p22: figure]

上端2個＋片側の側面2個

下端2個＋反対側の側面2個

中央の大きな配線口でUSB側板と区別する。穴の入口と樹脂面をそろえて圧入する。

最終更新日：2026年9月15日

27

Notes: 駆動側板へ8個：USB側板と同じ配置
中央の大きな配線口でUSB側板と区別する。穴の入口と樹脂面をそろえて圧入する。
https://github.com/dainakai/plate-lift-control
https://www.pololu.com/product/3130/specs
https://www.pololu.com/docs/0J71/4.2
https://www.pololu.com/docs/0J71/4.14
https://www.fa.omron.co.jp/product/item/SS-01GL13-E/

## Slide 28

インサートの取り付け

ヒューズ側板へベース固定用の2個

01

ヒューズの大きな丸穴の下にある、横並びの2穴を探す。

平らな外側の面から、内側の厚い受けへ向けて圧入する。

02

03

四隅のM3通し穴は側板固定用。インサートを入れない。

確認：ベースから入るM3×12を受ける。インサートの入口を外面とそろえる。

M3インサート ×2

最終更新日：2026年9月15日

28

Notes: ヒューズ側板へベース固定用の2個
M3インサート ×2
ヒューズの大きな丸穴の下にある、横並びの2穴を探す。
平らな外側の面から、内側の厚い受けへ向けて圧入する。
四隅のM3通し穴は側板固定用。インサートを入れない。
ベースから入るM3×12を受ける。インサートの入口を外面とそろえる。
https://github.com/dainakai/plate-lift-control
https://www.pololu.com/product/3130/specs
https://www.pololu.com/docs/0J71/4.2
https://www.pololu.com/docs/0J71/4.14
https://www.fa.omron.co.jp/product/item/SS-01GL13-E/

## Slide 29

インサートの取り付け

ホルダー本体の側面へ2個

01

高い柱の側面にある、縦に並ぶ2穴を探す。

この側面から圧入し、入口を樹脂面とそろえる。

02

03

この面へ接続腕を重ね、反対側からM3×12を2本入れる。

確認：前枠を留める4か所の六角穴にはM3ナットを入れる。

ガラスホルダー本体 ／ M3インサート ×2

最終更新日：2026年9月15日

29

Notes: ホルダー本体の側面へ2個
ガラスホルダー本体 ／ M3インサート ×2
高い柱の側面にある、縦に並ぶ2穴を探す。
この側面から圧入し、入口を樹脂面とそろえる。
この面へ接続腕を重ね、反対側からM3×12を2本入れる。
前枠を留める4か所の六角穴にはM3ナットを入れる。
https://github.com/dainakai/plate-lift-control
https://www.pololu.com/product/3130/specs
https://www.pololu.com/docs/0J71/4.2
https://www.pololu.com/docs/0J71/4.14
https://www.fa.omron.co.jp/product/item/SS-01GL13-E/

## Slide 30

インサートの取り付け

インサートの圧入と確認

01

採用したφ4.2 mmの試験片と同じ材料と加熱条件を使う。

穴の軸に沿ってまっすぐ圧入し、入口を樹脂面とそろえる。

02

03

室温まで冷ましてからM3ねじを入れ、空回りや傾きがないかを確認する。

確認：位置図と照合し、機構4部品へ8個、箱3部品へ18個。合計26個。

M3インサート：合計26個（外径4.6、長さ5.7 mm）

最終更新日：2026年9月15日

30

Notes: インサートの圧入と確認
M3インサート：合計26個（外径4.6、長さ5.7 mm）
採用したφ4.2 mmの試験片と同じ材料と加熱条件を使う。
穴の軸に沿ってまっすぐ圧入し、入口を樹脂面とそろえる。
室温まで冷ましてからM3ねじを入れ、空回りや傾きがないかを確認する。
位置図と照合し、機構4部品へ8個、箱3部品へ18個。合計26個。
https://github.com/dainakai/plate-lift-control
https://www.pololu.com/product/3130/specs
https://www.pololu.com/docs/0J71/4.2
https://www.pololu.com/docs/0J71/4.14
https://www.fa.omron.co.jp/product/item/SS-01GL13-E/

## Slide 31

モーター・軸受・送りねじ

カップリングをモーターへ仮止め

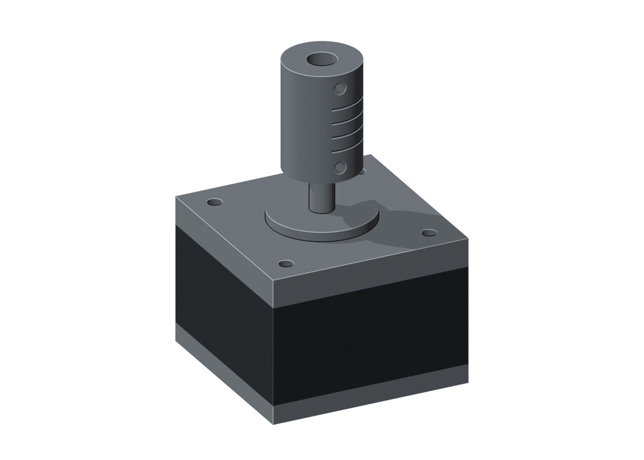
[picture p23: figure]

01

カップリングのφ5穴を下、φ6穴を上へ向ける。

φ5側をモーター軸へ入れる。下面は取付面から公称11 mm上。

02

03

止めねじを軽く締め、モーターと一緒に持てる状態にする。

確認：送りねじを入れて芯と軸端の隙間を確認してから本締めする。

C-42STM01 ／ CPL16-5-6

最終更新日：2026年9月15日

31

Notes: カップリングをモーターへ仮止め
C-42STM01 ／ CPL16-5-6
カップリングのφ5穴を下、φ6穴を上へ向ける。
φ5側をモーター軸へ入れる。下面は取付面から公称11 mm上。
止めねじを軽く締め、モーターと一緒に持てる状態にする。
送りねじを入れて芯と軸端の隙間を確認してから本締めする。
https://github.com/dainakai/plate-lift-control
https://www.pololu.com/product/3130/specs
https://www.pololu.com/docs/0J71/4.2
https://www.pololu.com/docs/0J71/4.14
https://www.fa.omron.co.jp/product/item/SS-01GL13-E/

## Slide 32

モーター・軸受・送りねじ

モーターとカップリングを一緒に挿入

U字開口を手前へ向ける

取付面を合わせて奥まで差し込む

配線を背面へ出す。モーターのφ22の出っ張りを、U字開口から通す。

最終更新日：2026年9月15日

32

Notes: モーターとカップリングを一緒に挿入
配線を背面へ出す。モーターのφ22の出っ張りを、U字開口から通す。
https://github.com/dainakai/plate-lift-control
https://www.pololu.com/product/3130/specs
https://www.pololu.com/docs/0J71/4.2
https://www.pololu.com/docs/0J71/4.14
https://www.fa.omron.co.jp/product/item/SS-01GL13-E/

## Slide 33

モーター・軸受・送りねじ

モーターをM3×8で固定

軸受座を省略した拡大・ねじを離して表示

01

モーター座と軸受座の間の開口から、M3×8を4本入れる。

ねじ先を座の上へ持ち上げ、穴の上で下ろしてモーターへ掛ける。

02

03

短辺20 mm以下のL形六角レンチを入れ、対角に締める。

確認：奥の2本には縦溝を使う。ねじ込みは公称4 mm。

M3×8 ×4 ／ 2.5 mm L形六角レンチ

最終更新日：2026年9月15日

33

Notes: モーターをM3×8で固定
M3×8 ×4 ／ 2.5 mm L形六角レンチ
モーター座と軸受座の間の開口から、M3×8を4本入れる。
ねじ先を座の上へ持ち上げ、穴の上で下ろしてモーターへ掛ける。
短辺20 mm以下のL形六角レンチを入れ、対角に締める。
奥の2本には縦溝を使う。ねじ込みは公称4 mm。
https://github.com/dainakai/plate-lift-control
https://www.pololu.com/product/3130/specs
https://www.pololu.com/docs/0J71/4.2
https://www.pololu.com/docs/0J71/4.14
https://www.fa.omron.co.jp/product/item/SS-01GL13-E/

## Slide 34

モーター・軸受・送りねじ

軸まわりの順番を先に確認

送りねじの上部を省略した分解図

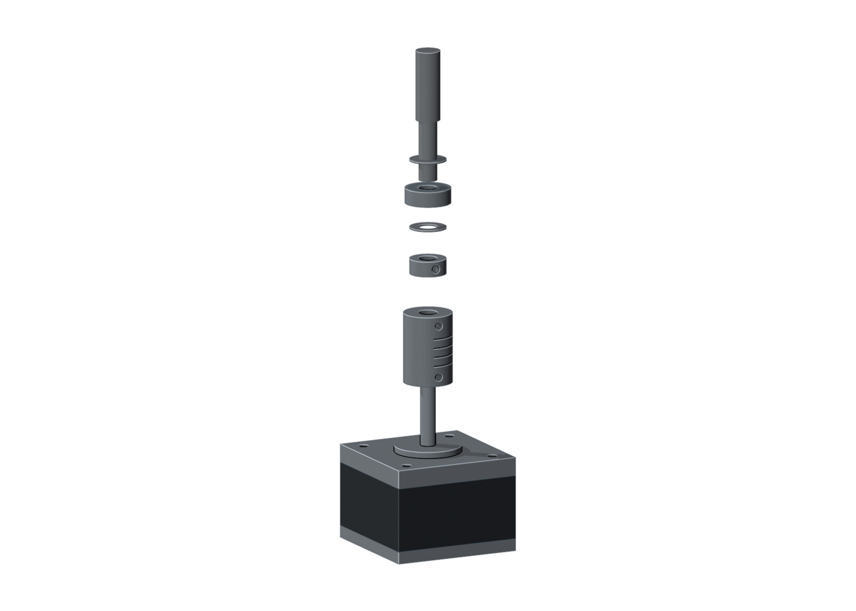
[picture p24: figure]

φ6の細い軸端を下へ。シム2枚はベアリングの上下に1枚ずつ。

送りねじ MTSRA8の段の肩

精密シム CIMR6-12-0.5

上

軸受 696ZZ

1

2

精密シム CIMR6-12-0.5

3

セットカラー PSCCJ6-5

4

カップリング CPL16-5-6

5

モーターのφ5軸

下

最終更新日：2026年9月15日

34

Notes: 軸まわりの順番を先に確認
φ6の細い軸端を下へ。シム2枚はベアリングの上下に1枚ずつ。
https://github.com/dainakai/plate-lift-control
https://www.pololu.com/product/3130/specs
https://www.pololu.com/docs/0J71/4.2
https://www.pololu.com/docs/0J71/4.14
https://www.fa.omron.co.jp/product/item/SS-01GL13-E/

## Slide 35

モーター・軸受・送りねじ

カラーと下シムを上から入れる

01

蓋を外した軸受座から、セットカラーを上から通す。

カラーをカップリングの上に仮置きし、中央をそろえる。

02

03

カラーの上に厚さ0.5 mmの下シムを置く。

確認：カラーは軸受座の下のφ12.4 mm部分へ収める。

PSCCJ6-5 ×1 ／ CIMR6-12-0.5 ×1

最終更新日：2026年9月15日

35

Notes: カラーと下シムを上から入れる
PSCCJ6-5 ×1 ／ CIMR6-12-0.5 ×1
蓋を外した軸受座から、セットカラーを上から通す。
カラーをカップリングの上に仮置きし、中央をそろえる。
カラーの上に厚さ0.5 mmの下シムを置く。
カラーは軸受座の下のφ12.4 mm部分へ収める。
https://github.com/dainakai/plate-lift-control
https://www.pololu.com/product/3130/specs
https://www.pololu.com/docs/0J71/4.2
https://www.pololu.com/docs/0J71/4.14
https://www.fa.omron.co.jp/product/item/SS-01GL13-E/

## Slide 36

モーター・軸受・送りねじ

696ZZを座へ入れる

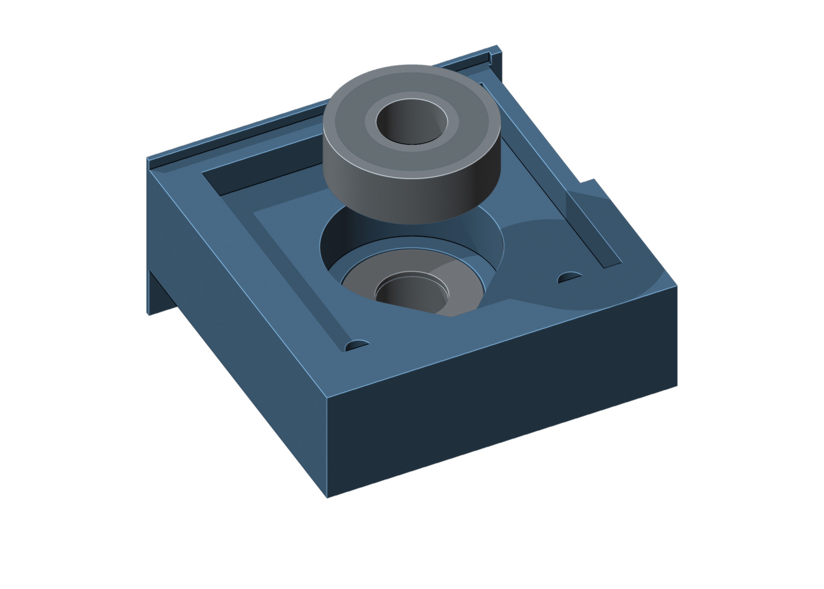
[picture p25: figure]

01

軸受座に残った糸引きやサポートを除く。

軸受を水平に持ち、外輪の周囲を押して上から入れる。

02

03

軸受が傾かず、内輪が軽く回ることを確かめる。

確認：軸受座は採用済みφ15.5 mm。強く押して割らない。

696ZZ ×1

最終更新日：2026年9月15日

36

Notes: 696ZZを座へ入れる
696ZZ ×1
軸受座に残った糸引きやサポートを除く。
軸受を水平に持ち、外輪の周囲を押して上から入れる。
軸受が傾かず、内輪が軽く回ることを確かめる。
軸受座は採用済みφ15.5 mm。強く押して割らない。
https://github.com/dainakai/plate-lift-control
https://www.pololu.com/product/3130/specs
https://www.pololu.com/docs/0J71/4.2
https://www.pololu.com/docs/0J71/4.14
https://www.fa.omron.co.jp/product/item/SS-01GL13-E/

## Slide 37

モーター・軸受・送りねじ

上シムと蓋を凹みに収める

01

軸受の上に、もう1枚の0.5 mmシムを置く。

既存の蓋を26.4×26.4 mmの凹みへ入れる。

02

03

座の下面でM2ナットを保持し、上からM2×12を3本締める。

確認：深さ3.2 mmの凹み。蓋の上面は周囲の縁より1 mm低い。

上シム ×1 ／ 軸受押さえ ／ M2×12・M2ナット 各3

最終更新日：2026年9月15日

37

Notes: 上シムと蓋を凹みに収める
上シム ×1 ／ 軸受押さえ ／ M2×12・M2ナット 各3
軸受の上に、もう1枚の0.5 mmシムを置く。
既存の蓋を26.4×26.4 mmの凹みへ入れる。
座の下面でM2ナットを保持し、上からM2×12を3本締める。
深さ3.2 mmの凹み。蓋の上面は周囲の縁より1 mm低い。
https://github.com/dainakai/plate-lift-control
https://www.pololu.com/product/3130/specs
https://www.pololu.com/docs/0J71/4.2
https://www.pololu.com/docs/0J71/4.14
https://www.fa.omron.co.jp/product/item/SS-01GL13-E/

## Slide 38

モーター・軸受・送りねじ

蓋が収まる深さを確認

凹みへ上から入れる

蓋の上面は周囲より1 mm低い

凹み26.4×26.4 mm・深さ3.2 mm。既存の26×26×厚さ2.2 mmの蓋を使う。

最終更新日：2026年9月15日

38

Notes: 蓋が収まる深さを確認
凹み26.4×26.4 mm・深さ3.2 mm。既存の26×26×厚さ2.2 mmの蓋を使う。
https://github.com/dainakai/plate-lift-control
https://www.pololu.com/product/3130/specs
https://www.pololu.com/docs/0J71/4.2
https://www.pololu.com/docs/0J71/4.14
https://www.fa.omron.co.jp/product/item/SS-01GL13-E/

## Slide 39

モーター・軸受・送りねじ

送りねじを上から通して固定

01

細いφ6の端を下へ向け、蓋・シム・軸受・カラーへ通す。

φ6端をカップリング上側へ入れ、軸端間に公称1 mmの隙間を保つ。

02

03

肩・シム・軸受・カラーをそろえ、軽く回る状態で止めねじを締める。

確認：キャリアを組む前に行う。軸を強く押し付けて締めない。

MTSRA8-120-S20-Q6 ／ カップリング・カラーの付属止めねじ

最終更新日：2026年9月15日

39

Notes: 送りねじを上から通して固定
MTSRA8-120-S20-Q6 ／ カップリング・カラーの付属止めねじ
細いφ6の端を下へ向け、蓋・シム・軸受・カラーへ通す。
φ6端をカップリング上側へ入れ、軸端間に公称1 mmの隙間を保つ。
肩・シム・軸受・カラーをそろえ、軽く回る状態で止めねじを締める。
キャリアを組む前に行う。軸を強く押し付けて締めない。
https://github.com/dainakai/plate-lift-control
https://www.pololu.com/product/3130/specs
https://www.pololu.com/docs/0J71/4.2
https://www.pololu.com/docs/0J71/4.14
https://www.fa.omron.co.jp/product/item/SS-01GL13-E/

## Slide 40

レールの取り付け

レールをまっすぐ固定する

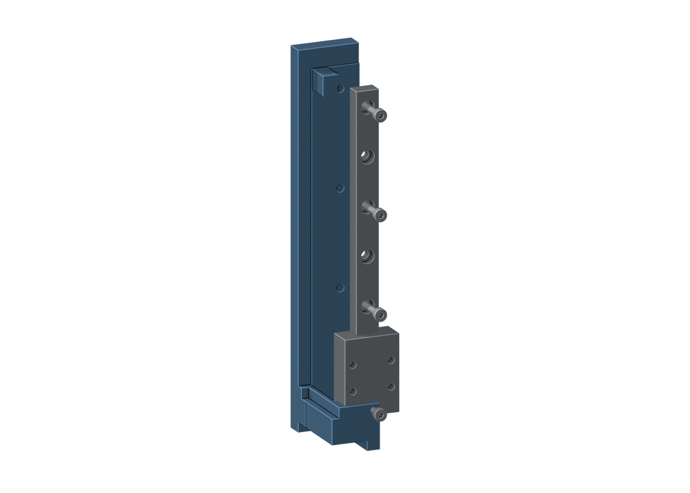
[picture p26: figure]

01

背面の4つの六角座へM2ナットを入れる。

レールの7穴のうち、端から1・3・5・7番を使う。

02

03

ブロックを動かし、レール側からM2×12を4本締める。

確認：ブロックをレールから抜かない。全域を滑らかに動くこと。

SSEB8-100 ×1組 ／ M2×12・M2ナット 各4

最終更新日：2026年9月15日

40

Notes: レールをまっすぐ固定する
SSEB8-100 ×1組 ／ M2×12・M2ナット 各4
背面の4つの六角座へM2ナットを入れる。
レールの7穴のうち、端から1・3・5・7番を使う。
ブロックを動かし、レール側からM2×12を4本締める。
ブロックをレールから抜かない。全域を滑らかに動くこと。
https://github.com/dainakai/plate-lift-control
https://www.pololu.com/product/3130/specs
https://www.pololu.com/docs/0J71/4.2
https://www.pololu.com/docs/0J71/4.14
https://www.fa.omron.co.jp/product/item/SS-01GL13-E/

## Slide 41

分割キャリアの組立

レールブロック取付板を固定

01

M3インサートが上を向くよう、取付板をブロックへ合わせる。

段のある大きい穴の奥から、M2×6を4本入れる。

02

03

4本を対角に締め、ブロックが滑らかに動くことを確認する。

確認：M2ナットは使わない。ブロックのねじ深さは2.5 mm。

レールブロック取付板 ／ M2×6 ×4

最終更新日：2026年9月15日

41

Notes: レールブロック取付板を固定
レールブロック取付板 ／ M2×6 ×4
M3インサートが上を向くよう、取付板をブロックへ合わせる。
段のある大きい穴の奥から、M2×6を4本入れる。
4本を対角に締め、ブロックが滑らかに動くことを確認する。
M2ナットは使わない。ブロックのねじ深さは2.5 mm。
https://github.com/dainakai/plate-lift-control
https://www.pololu.com/product/3130/specs
https://www.pololu.com/docs/0J71/4.2
https://www.pololu.com/docs/0J71/4.14
https://www.fa.omron.co.jp/product/item/SS-01GL13-E/

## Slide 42

分割キャリアの組立

MTSFR8を取付板へ固定

01

大きいフランジを上、細い胴を下へ向ける。

フランジ上面を取付板の下面へ当て、4穴を斜め45度にそろえる。

02

03

板の上からM4×14、フランジの下からM4ナットで留める。

確認：M4ナットの平らな面を黄銅の胴へ向ける。座金は入れない。

黄銅ナット取付板 ／ MTSFR8 ／ M4×14・M4ナット 各4

最終更新日：2026年9月15日

42

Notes: MTSFR8を取付板へ固定
黄銅ナット取付板 ／ MTSFR8 ／ M4×14・M4ナット 各4
大きいフランジを上、細い胴を下へ向ける。
フランジ上面を取付板の下面へ当て、4穴を斜め45度にそろえる。
板の上からM4×14、フランジの下からM4ナットで留める。
M4ナットの平らな面を黄銅の胴へ向ける。座金は入れない。
https://github.com/dainakai/plate-lift-control
https://www.pololu.com/product/3130/specs
https://www.pololu.com/docs/0J71/4.2
https://www.pololu.com/docs/0J71/4.14
https://www.fa.omron.co.jp/product/item/SS-01GL13-E/

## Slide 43

分割キャリアの組立

黄銅ナット取付板をレール側へ接続

01

取付板を持ち、MTSFR8へ送りねじ上端を軽く掛ける。

送りねじを手で回し、板をレールブロック取付板の上面まで下げる。

02

03

上からM3×12を2本入れ、レール側のインサートへ固定する。

確認：ねじ山を斜めに掛けない。手回し68 mm全域で引っ掛からないこと。

黄銅ナット取付板 ／ M3×12 ×2

最終更新日：2026年9月15日

43

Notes: 黄銅ナット取付板をレール側へ接続
黄銅ナット取付板 ／ M3×12 ×2
取付板を持ち、MTSFR8へ送りねじ上端を軽く掛ける。
送りねじを手で回し、板をレールブロック取付板の上面まで下げる。
上からM3×12を2本入れ、レール側のインサートへ固定する。
ねじ山を斜めに掛けない。手回し68 mm全域で引っ掛からないこと。
https://github.com/dainakai/plate-lift-control
https://www.pololu.com/product/3130/specs
https://www.pololu.com/docs/0J71/4.2
https://www.pololu.com/docs/0J71/4.14
https://www.fa.omron.co.jp/product/item/SS-01GL13-E/

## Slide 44

分割キャリアの組立

接続腕を黄銅ナット取付板へ固定

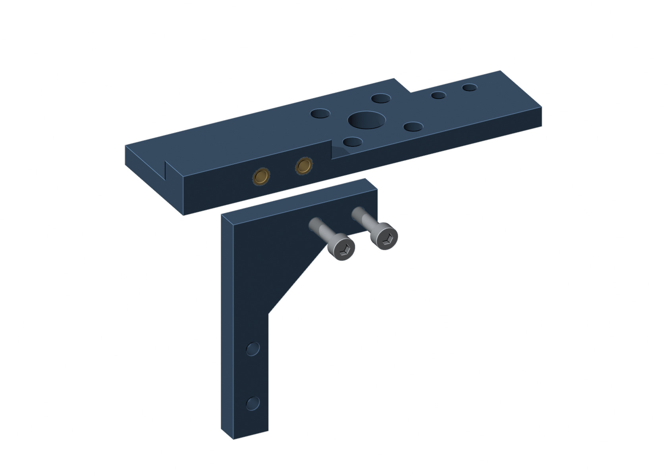
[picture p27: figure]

01

接続腕の横に並ぶ2穴を、取付板の側面へ合わせる。

腕の外側からM3×12を2本入れ、取付板のインサートへ掛ける。

02

03

合わせ面を密着させて締め、下の縦2穴をホルダー用に残す。

確認：横2穴は取付板、縦2穴はガラスホルダーとの接続。

ガラスホルダー接続腕 ／ M3×12 ×2

最終更新日：2026年9月15日

44

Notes: 接続腕を黄銅ナット取付板へ固定
ガラスホルダー接続腕 ／ M3×12 ×2
接続腕の横に並ぶ2穴を、取付板の側面へ合わせる。
腕の外側からM3×12を2本入れ、取付板のインサートへ掛ける。
合わせ面を密着させて締め、下の縦2穴をホルダー用に残す。
横2穴は取付板、縦2穴はガラスホルダーとの接続。
https://github.com/dainakai/plate-lift-control
https://www.pololu.com/product/3130/specs
https://www.pololu.com/docs/0J71/4.2
https://www.pololu.com/docs/0J71/4.14
https://www.fa.omron.co.jp/product/item/SS-01GL13-E/

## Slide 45

分割キャリアの組立

3部品を組み合わせたキャリア

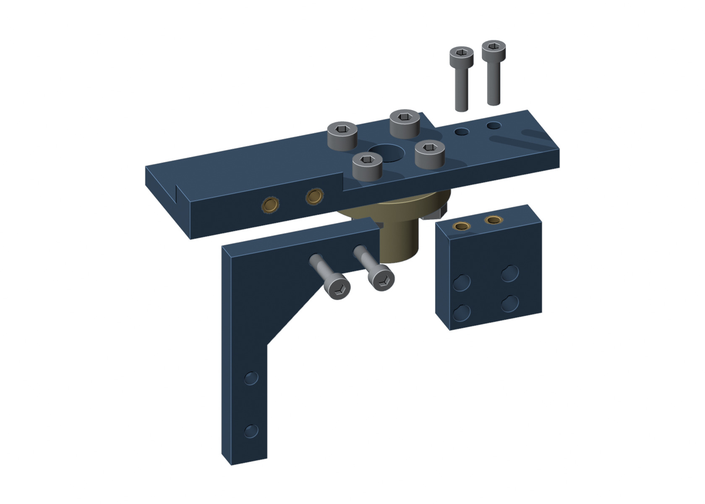
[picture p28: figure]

分解図：ねじと合わせ面を確認

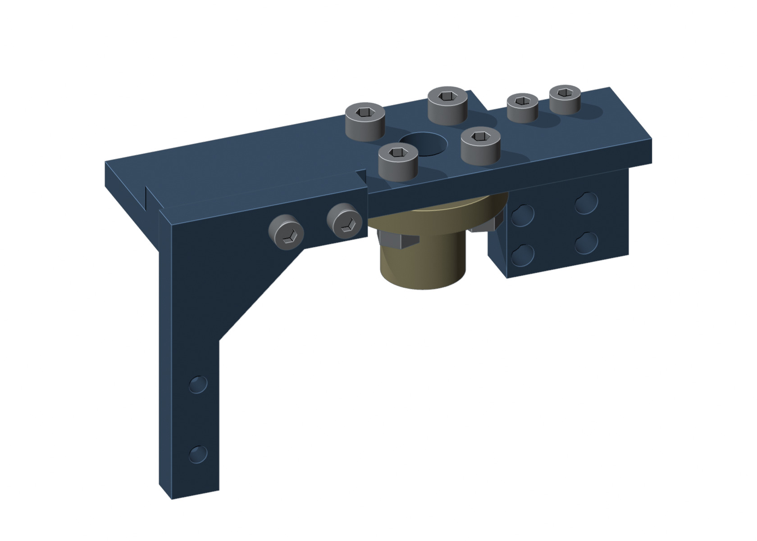
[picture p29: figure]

組付け後：すべての面を密着

小さい取付板をレールへ、広い取付板をMTSFR8へ、縦の腕をホルダーへつなぐ。

最終更新日：2026年9月15日

45

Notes: 3部品を組み合わせたキャリア
小さい取付板をレールへ、広い取付板をMTSFR8へ、縦の腕をホルダーへつなぐ。
https://github.com/dainakai/plate-lift-control
https://www.pololu.com/product/3130/specs
https://www.pololu.com/docs/0J71/4.2
https://www.pololu.com/docs/0J71/4.14
https://www.fa.omron.co.jp/product/item/SS-01GL13-E/

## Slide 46

検出部を組む

上下リミットの取り付け位置

01

2個のSS-01GL13-Eを、フレーム上下の長穴へ取り付ける。

下側はレバーが上、上側はレバーが下を向くようにする。

02

03

黄銅ナット取付板の下面・上面が、それぞれレバー先端へ当たる。

確認：スイッチ本体と配線は固定側。独立した爪は取り付けない。

OMRON SS-01GL13-E ×2（周辺を一部省略）

最終更新日：2026年9月15日

46

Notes: 上下リミットの取り付け位置
OMRON SS-01GL13-E ×2（周辺を一部省略）
2個のSS-01GL13-Eを、フレーム上下の長穴へ取り付ける。
下側はレバーが上、上側はレバーが下を向くようにする。
黄銅ナット取付板の下面・上面が、それぞれレバー先端へ当たる。
スイッチ本体と配線は固定側。独立した爪は取り付けない。
https://github.com/dainakai/plate-lift-control
https://www.pololu.com/product/3130/specs
https://www.pololu.com/docs/0J71/4.2
https://www.pololu.com/docs/0J71/4.14
https://www.fa.omron.co.jp/product/item/SS-01GL13-E/

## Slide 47

検出部を組む

リミットスイッチを長穴に固定

01

9.5 mm間隔の2つの長穴へ、スイッチの穴を合わせる。

スイッチ側からM2×16を入れ、背面へM2ナットを掛ける。

02

03

上下へ調整できる強さで仮止めし、復帰高さを合わせて本締めする。

確認：裏ナットは背面の外側。M2×16を各2本、既存部材で固定する。

SS-01GL13-E ×2 ／ M2×16・M2ナット 各4

最終更新日：2026年9月15日

47

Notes: リミットスイッチを長穴に固定
SS-01GL13-E ×2 ／ M2×16・M2ナット 各4
9.5 mm間隔の2つの長穴へ、スイッチの穴を合わせる。
スイッチ側からM2×16を入れ、背面へM2ナットを掛ける。
上下へ調整できる強さで仮止めし、復帰高さを合わせて本締めする。
裏ナットは背面の外側。M2×16を各2本、既存部材で固定する。
https://github.com/dainakai/plate-lift-control
https://www.pololu.com/product/3130/specs
https://www.pololu.com/docs/0J71/4.2
https://www.pololu.com/docs/0J71/4.14
https://www.fa.omron.co.jp/product/item/SS-01GL13-E/

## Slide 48

検出部を組む

下側：レバーを上へ向ける

01

金属レバーは本体の上、3つの端子は下へ向ける。

曲がった先端を、黄銅ナット取付板の下面の下へ置く。

02

03

キャリアが下がると、板の下面がレバーを下へ押す。

確認：板は曲がった金属レバーへ当てる。黒い本体や端子に当てない。

下端リミット SS-01GL13-E
オレンジ：黄銅ナット取付板の一部

最終更新日：2026年9月15日

48

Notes: 下側：レバーを上へ向ける
下端リミット SS-01GL13-E
オレンジ：黄銅ナット取付板の一部
金属レバーは本体の上、3つの端子は下へ向ける。
曲がった先端を、黄銅ナット取付板の下面の下へ置く。
キャリアが下がると、板の下面がレバーを下へ押す。
板は曲がった金属レバーへ当てる。黒い本体や端子に当てない。
https://github.com/dainakai/plate-lift-control
https://www.pololu.com/product/3130/specs
https://www.pololu.com/docs/0J71/4.2
https://www.pololu.com/docs/0J71/4.14
https://www.fa.omron.co.jp/product/item/SS-01GL13-E/

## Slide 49

検出部を組む

上側：レバーを下へ向ける

01

下側のスイッチを上下反転した向き。端子は上、レバーは下。

曲がった先端を、黄銅ナット取付板の上面の上へ置く。

02

03

キャリアが上がると、板の上面がレバーを上へ押す。

確認：板は曲がった金属レバーへ当てる。黒い本体や端子に当てない。

上端リミット SS-01GL13-E
オレンジ：黄銅ナット取付板の一部

最終更新日：2026年9月15日

49

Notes: 上側：レバーを下へ向ける
上端リミット SS-01GL13-E
オレンジ：黄銅ナット取付板の一部
下側のスイッチを上下反転した向き。端子は上、レバーは下。
曲がった先端を、黄銅ナット取付板の上面の上へ置く。
キャリアが上がると、板の上面がレバーを上へ押す。
板は曲がった金属レバーへ当てる。黒い本体や端子に当てない。
https://github.com/dainakai/plate-lift-control
https://www.pololu.com/product/3130/specs
https://www.pololu.com/docs/0J71/4.2
https://www.pololu.com/docs/0J71/4.14
https://www.fa.omron.co.jp/product/item/SS-01GL13-E/

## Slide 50

ガラスホルダーを組む

支持ねじをホルダーへ入れる

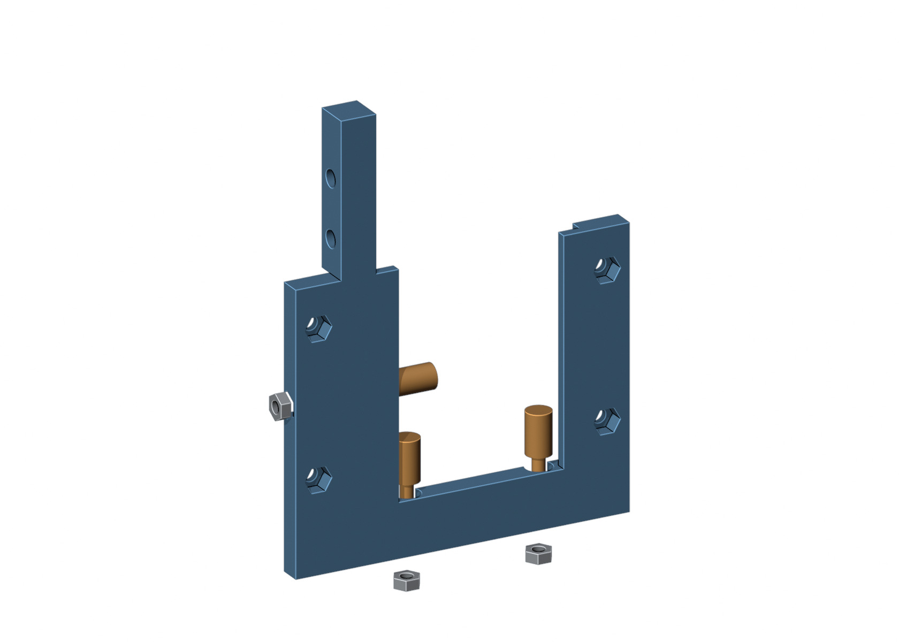
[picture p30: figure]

01

下側2本は枠の内側から差し、柔らかい先端を上へ向ける。

側面1本は内側から外へ差し、柔らかい先端をガラス側へ向ける。

02

03

ねじ先にM3ナットを掛け、外側の六角座へ収める。

確認：シリコンねじと呼んでいた部品は、ウレタン先端のUSLL6。

USLL6 ×3 ／ M3ナット ×3（穴から離した分解図）

最終更新日：2026年9月15日

50

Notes: 支持ねじをホルダーへ入れる
USLL6 ×3 ／ M3ナット ×3（穴から離した分解図）
下側2本は枠の内側から差し、柔らかい先端を上へ向ける。
側面1本は内側から外へ差し、柔らかい先端をガラス側へ向ける。
ねじ先にM3ナットを掛け、外側の六角座へ収める。
シリコンねじと呼んでいた部品は、ウレタン先端のUSLL6。
https://github.com/dainakai/plate-lift-control
https://www.pololu.com/product/3130/specs
https://www.pololu.com/docs/0J71/4.2
https://www.pololu.com/docs/0J71/4.14
https://www.fa.omron.co.jp/product/item/SS-01GL13-E/

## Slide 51

ガラスホルダーを組む

前枠を合わせて深い溝を作る

01

本体の背面4か所へM3ナットを入れる。支持ねじ用とは別。

前枠を重ね、前側からM3×8を4本入れる。

02

03

合わせ面が密着するまで、対角に少しずつ締める。

確認：採用溝幅2.9 mm、ガラス端への掛かり5 mm。締めて溝を潰さない。

ホルダー本体＋前枠 ／ M3×8・M3ナット 各4

最終更新日：2026年9月15日

51

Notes: 前枠を合わせて深い溝を作る
ホルダー本体＋前枠 ／ M3×8・M3ナット 各4
本体の背面4か所へM3ナットを入れる。支持ねじ用とは別。
前枠を重ね、前側からM3×8を4本入れる。
合わせ面が密着するまで、対角に少しずつ締める。
採用溝幅2.9 mm、ガラス端への掛かり5 mm。締めて溝を潰さない。
https://github.com/dainakai/plate-lift-control
https://www.pololu.com/product/3130/specs
https://www.pololu.com/docs/0J71/4.2
https://www.pololu.com/docs/0J71/4.14
https://www.fa.omron.co.jp/product/item/SS-01GL13-E/

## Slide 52

ホルダーとキャリアの接続

ホルダーとキャリアの合わせ面

ホルダー側：縦2穴のインサート

接続腕側：厚さ6 mmの縦2穴

オレンジ色の合わせ面を重ねる。横に並ぶ2穴は黄銅ナット取付板との接続用。

最終更新日：2026年9月15日

52

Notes: ホルダーとキャリアの合わせ面
オレンジ色の合わせ面を重ねる。横に並ぶ2穴は黄銅ナット取付板との接続用。
https://github.com/dainakai/plate-lift-control
https://www.pololu.com/product/3130/specs
https://www.pololu.com/docs/0J71/4.2
https://www.pololu.com/docs/0J71/4.14
https://www.fa.omron.co.jp/product/item/SS-01GL13-E/

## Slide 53

ホルダーとキャリアの接続

M3×12でつなぐ順番

01

接続腕の縦2穴と、ホルダーのインサート2穴を合わせる。

腕側からM3×12を2本通し、ホルダー内のインサートへ掛ける。

02

03

2本とも軽くねじ込んでから、合わせ面を密着させて締める。

確認：接続腕にはインサートを入れない。頭は腕側、ねじ先はホルダー側。

接続腕・ガラスホルダー ／ M3×12 ×2

最終更新日：2026年9月15日

53

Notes: M3×12でつなぐ順番
接続腕・ガラスホルダー ／ M3×12 ×2
接続腕の縦2穴と、ホルダーのインサート2穴を合わせる。
腕側からM3×12を2本通し、ホルダー内のインサートへ掛ける。
2本とも軽くねじ込んでから、合わせ面を密着させて締める。
接続腕にはインサートを入れない。頭は腕側、ねじ先はホルダー側。
https://github.com/dainakai/plate-lift-control
https://www.pololu.com/product/3130/specs
https://www.pololu.com/docs/0J71/4.2
https://www.pololu.com/docs/0J71/4.14
https://www.fa.omron.co.jp/product/item/SS-01GL13-E/

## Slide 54

ホルダーとキャリアの接続

接続後の外観とねじの断面

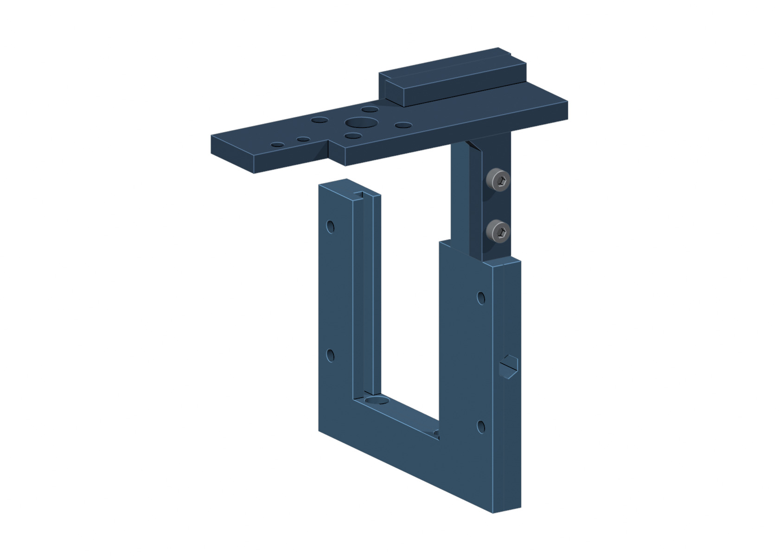
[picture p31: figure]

組付け後：腕側にM3ねじ頭2個

断面：頭・6 mmの腕・インサートの順

断面図は周囲を省略した表示。相手側のインサートを普通のナットへ置き換えない。

最終更新日：2026年9月15日

54

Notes: 接続後の外観とねじの断面
断面図は周囲を省略した表示。相手側のインサートを普通のナットへ置き換えない。
https://github.com/dainakai/plate-lift-control
https://www.pololu.com/product/3130/specs
https://www.pololu.com/docs/0J71/4.2
https://www.pololu.com/docs/0J71/4.14
https://www.fa.omron.co.jp/product/item/SS-01GL13-E/

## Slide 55

土台を組む

機構をベースへ固定する

01

駆動フレーム下端の2穴を、ベースの取付壁の2穴へ合わせる。

電子箱と同じ側からM3×12を2本通し、フレームのインサートへ留める。

02

03

ベースを平らな台へ置き、傾きや浮きがないように締める。

確認：底面が浮かず、ガラスと駆動フレームの位置が完成図と一致する。

ベース・駆動フレーム下端（拡大） ／ M3×12 ×2

最終更新日：2026年9月15日

55

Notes: 機構をベースへ固定する
ベース・駆動フレーム下端（拡大） ／ M3×12 ×2
駆動フレーム下端の2穴を、ベースの取付壁の2穴へ合わせる。
電子箱と同じ側からM3×12を2本通し、フレームのインサートへ留める。
ベースを平らな台へ置き、傾きや浮きがないように締める。
底面が浮かず、ガラスと駆動フレームの位置が完成図と一致する。
https://github.com/dainakai/plate-lift-control
https://www.pololu.com/product/3130/specs
https://www.pololu.com/docs/0J71/4.2
https://www.pololu.com/docs/0J71/4.14
https://www.fa.omron.co.jp/product/item/SS-01GL13-E/

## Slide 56

電子箱を組み立てる

電子箱はベースの外で組み始める

01

6枚の板を穴の形で区別する。インサートは先に入れておく。

まず底板とUSB側板・駆動側板をつなぐ。底のねじは下から締める。

02

03

左右の側板を開けて配線し、最後に天板を付けてベースへ載せる。

確認：この図は6枚を離した分解図。組立後の外形は68×63×83 mm。

底板・天板・USB側板・駆動側板・ヒューズ側板・電源側板

最終更新日：2026年9月15日

56

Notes: 電子箱はベースの外で組み始める
底板・天板・USB側板・駆動側板・ヒューズ側板・電源側板
6枚の板を穴の形で区別する。インサートは先に入れておく。
まず底板とUSB側板・駆動側板をつなぐ。底のねじは下から締める。
左右の側板を開けて配線し、最後に天板を付けてベースへ載せる。
この図は6枚を離した分解図。組立後の外形は68×63×83 mm。
https://github.com/dainakai/plate-lift-control
https://www.pololu.com/product/3130/specs
https://www.pololu.com/docs/0J71/4.2
https://www.pololu.com/docs/0J71/4.14
https://www.fa.omron.co.jp/product/item/SS-01GL13-E/

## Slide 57

電子箱を組み立てる

ガラスと電子箱の配置を確認

ガラス正面：フレームが面を遮らない

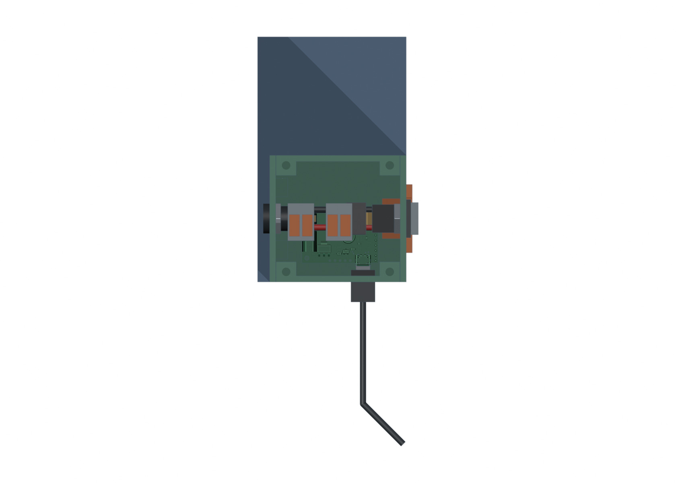
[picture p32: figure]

上から：電子箱はベース端へ収まる

ベースの短手は74 mm。USB側が外端、配線口が駆動フレーム側。フレームとの隙間は9 mm。

最終更新日：2026年9月15日

57

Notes: ガラスと電子箱の配置を確認
ベースの短手は74 mm。USB側が外端、配線口が駆動フレーム側。フレームとの隙間は9 mm。
https://github.com/dainakai/plate-lift-control
https://www.pololu.com/product/3130/specs
https://www.pololu.com/docs/0J71/4.2
https://www.pololu.com/docs/0J71/4.14
https://www.fa.omron.co.jp/product/item/SS-01GL13-E/

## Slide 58

電子箱を組み立てる

Tic基板を2つの受けへ載せる

01

底板だけを置き、Micro-B端子をUSB側板の開口へ向ける。

2つの基板穴を樹脂受けに合わせ、M2×6を入れる。

02

03

φ1.6の樹脂下穴へゆっくりねじを立て、基板が動かない程度に締める。

確認：基板を反らせない。部品面やはんだへ金属工具を落とさない。

Pololu 3130 Tic T825 ／ M2×6 ×2

最終更新日：2026年9月15日

58

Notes: Tic基板を2つの受けへ載せる
Pololu 3130 Tic T825 ／ M2×6 ×2
底板だけを置き、Micro-B端子をUSB側板の開口へ向ける。
2つの基板穴を樹脂受けに合わせ、M2×6を入れる。
φ1.6の樹脂下穴へゆっくりねじを立て、基板が動かない程度に締める。
基板を反らせない。部品面やはんだへ金属工具を落とさない。
https://github.com/dainakai/plate-lift-control
https://www.pololu.com/product/3130/specs
https://www.pololu.com/docs/0J71/4.2
https://www.pololu.com/docs/0J71/4.14
https://www.fa.omron.co.jp/product/item/SS-01GL13-E/

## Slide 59

電子箱を組み立てる

底板にUSB側板と駆動側板を留める

01

USBの小さな開口側にUSB側板、反対側に駆動側板を置く。

底板の裏から4本を通し、両側板の下端インサートへ軽く締める。

02

03

板の外縁をそろえて本締めする。ねじ頭は底板の凹みに収める。

確認：底板の裏が平らになること。Ticや配線を下敷きにして裏返さない。

M3×8 ×4（底板の裏側から）

最終更新日：2026年9月15日

59

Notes: 底板にUSB側板と駆動側板を留める
M3×8 ×4（底板の裏側から）
USBの小さな開口側にUSB側板、反対側に駆動側板を置く。
底板の裏から4本を通し、両側板の下端インサートへ軽く締める。
板の外縁をそろえて本締めする。ねじ頭は底板の凹みに収める。
底板の裏が平らになること。Ticや配線を下敷きにして裏返さない。
https://github.com/dainakai/plate-lift-control
https://www.pololu.com/product/3130/specs
https://www.pololu.com/docs/0J71/4.2
https://www.pololu.com/docs/0J71/4.14
https://www.fa.omron.co.jp/product/item/SS-01GL13-E/

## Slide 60

電子箱を組み立てる

USBプラグを挿して空間を確認

01

Micro-Bを背面開口から差し、基板の端子へまっすぐ接続する。

プラグ樹脂部12×7.5 mmが開口の縁へ押されないことを確認。

02

03

基板端から約70 mmは急に曲げず、ケーブルを外へ逃がす。

確認：USBは通信。モーター用DC電源は別に接続する（24 V以下、21.2 Vでも可）。

ELECOM U2C-AMB10BK（USB-A–Micro-B）

最終更新日：2026年9月15日

60

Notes: USBプラグを挿して空間を確認
ELECOM U2C-AMB10BK（USB-A–Micro-B）
Micro-Bを背面開口から差し、基板の端子へまっすぐ接続する。
プラグ樹脂部12×7.5 mmが開口の縁へ押されないことを確認。
基板端から約70 mmは急に曲げず、ケーブルを外へ逃がす。
USBは通信。モーター用DC電源は別に接続する（24 V以下、21.2 Vでも可）。
https://github.com/dainakai/plate-lift-control
https://www.pololu.com/product/3130/specs
https://www.pololu.com/docs/0J71/4.2
https://www.pololu.com/docs/0J71/4.14
https://www.fa.omron.co.jp/product/item/SS-01GL13-E/

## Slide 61

電子箱を組み立てる

XT60電源口をパネル下側へ

01

既設の赤黒線を先に通し、フランジをパネル外側へ当てる。

外側からM2×8を2本入れ、箱側のM2ナットで固定する。

02

03

20.2×12.2 mmの開口に胴が収まり、フランジが板に当たるか確認。

確認：穴ピッチ25 mm。M3ナットは胴に干渉するため使わない。

LINSYRC XT60E-F ／ M2×8・M2ナット 各2

最終更新日：2026年9月15日

61

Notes: XT60電源口をパネル下側へ
LINSYRC XT60E-F ／ M2×8・M2ナット 各2
既設の赤黒線を先に通し、フランジをパネル外側へ当てる。
外側からM2×8を2本入れ、箱側のM2ナットで固定する。
20.2×12.2 mmの開口に胴が収まり、フランジが板に当たるか確認。
穴ピッチ25 mm。M3ナットは胴に干渉するため使わない。
https://github.com/dainakai/plate-lift-control
https://www.pololu.com/product/3130/specs
https://www.pololu.com/docs/0J71/4.2
https://www.pololu.com/docs/0J71/4.14
https://www.fa.omron.co.jp/product/item/SS-01GL13-E/

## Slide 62

電子箱を組み立てる

主電源スイッチを上側へ

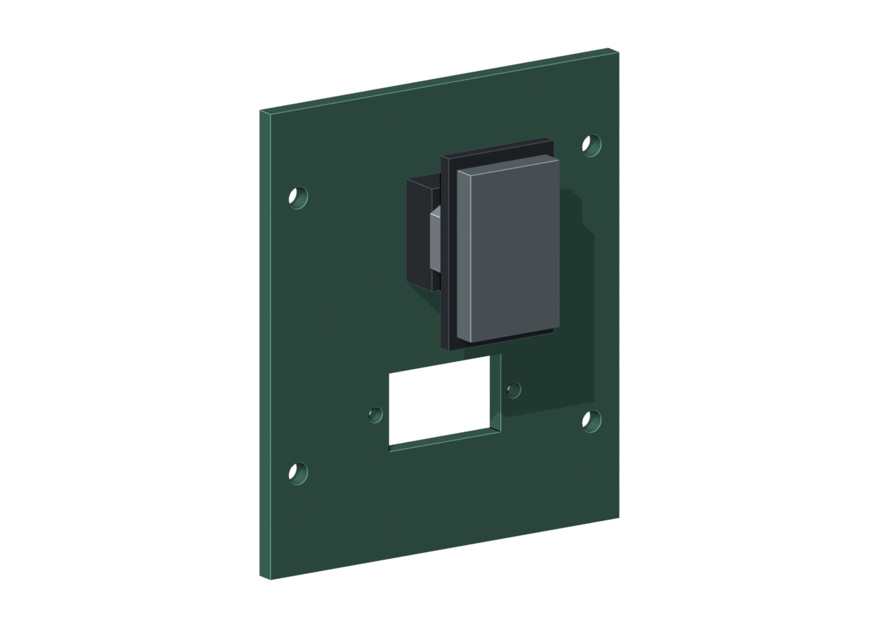
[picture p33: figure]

01

付属ナットを外し、スイッチをパネル外側からφ12.4穴へ入れる。

ON/OFF表示を読みやすい向きへそろえる。

02

03

箱の内側から付属ナットを戻し、パネルを挟んで固定する。

確認：固定するのは付属ナット。M3ナットや接着剤は使わない。

エーモン3214 ／ 付属取付ナット

最終更新日：2026年9月15日

62

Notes: 主電源スイッチを上側へ
エーモン3214 ／ 付属取付ナット
付属ナットを外し、スイッチをパネル外側からφ12.4穴へ入れる。
ON/OFF表示を読みやすい向きへそろえる。
箱の内側から付属ナットを戻し、パネルを挟んで固定する。
固定するのは付属ナット。M3ナットや接着剤は使わない。
https://github.com/dainakai/plate-lift-control
https://www.pololu.com/product/3130/specs
https://www.pololu.com/docs/0J71/4.2
https://www.pololu.com/docs/0J71/4.14
https://www.fa.omron.co.jp/product/item/SS-01GL13-E/

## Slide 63

電子箱を組み立てる

ヒューズホルダーを箱の側面へ

01

側板を外した状態で、キャップ側を外へ向けてφ13.0穴へ入れる。

箱の内側からナットを回し、厚さ3 mmの壁を挟む。

02

03

キャップを外せる空間と、内側のはんだ端子の空間を確保する。

確認：取付ナットと、ヒューズ交換用キャップを取り違えない。

OHM KIT-NR312 ／ 付属取付ナット

最終更新日：2026年9月15日

63

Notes: ヒューズホルダーを箱の側面へ
OHM KIT-NR312 ／ 付属取付ナット
側板を外した状態で、キャップ側を外へ向けてφ13.0穴へ入れる。
箱の内側からナットを回し、厚さ3 mmの壁を挟む。
キャップを外せる空間と、内側のはんだ端子の空間を確保する。
取付ナットと、ヒューズ交換用キャップを取り違えない。
https://github.com/dainakai/plate-lift-control
https://www.pololu.com/product/3130/specs
https://www.pololu.com/docs/0J71/4.2
https://www.pololu.com/docs/0J71/4.14
https://www.fa.omron.co.jp/product/item/SS-01GL13-E/

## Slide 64

電子箱を組み立てる

2 Aのガラス管ヒューズを入れる

01

DC電源とUSBを外し、ホルダー外側のキャップを開ける。

金属端の定格表示が2 Aのヒューズを選ぶ。

02

03

ホルダーの受けに入れ、キャップを元へ戻す。

確認：別定格を選ばない。初回配線チェックまでは抜いておいてよい。

エーモン3665の2 A ／ 5.2×20 mm

最終更新日：2026年9月15日

64

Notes: 2 Aのガラス管ヒューズを入れる
エーモン3665の2 A ／ 5.2×20 mm
DC電源とUSBを外し、ホルダー外側のキャップを開ける。
金属端の定格表示が2 Aのヒューズを選ぶ。
ホルダーの受けに入れ、キャップを元へ戻す。
別定格を選ばない。初回配線チェックまでは抜いておいてよい。
https://github.com/dainakai/plate-lift-control
https://www.pololu.com/product/3130/specs
https://www.pololu.com/docs/0J71/4.2
https://www.pololu.com/docs/0J71/4.14
https://www.fa.omron.co.jp/product/item/SS-01GL13-E/

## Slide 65

電子箱を組み立てる

WAGOは配線とともに保持

01

2個に正極用と0 V用のラベルを付け、それぞれの線を中継する。

専用の受け台はない。箱の空いた所へ、レバーを操作できる向きで収める。

02

03

出入りする線を配線束へ留め、コネクタが基板へ落ち込まないよう保持する。

確認：レバーを結束バンドで押さえない。ふたで押し込まない。

WAGO 221-412／WFR-2BP ×2

最終更新日：2026年9月15日

65

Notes: WAGOは配線とともに保持
WAGO 221-412／WFR-2BP ×2
2個に正極用と0 V用のラベルを付け、それぞれの線を中継する。
専用の受け台はない。箱の空いた所へ、レバーを操作できる向きで収める。
出入りする線を配線束へ留め、コネクタが基板へ落ち込まないよう保持する。
レバーを結束バンドで押さえない。ふたで押し込まない。
https://github.com/dainakai/plate-lift-control
https://www.pololu.com/product/3130/specs
https://www.pololu.com/docs/0J71/4.2
https://www.pololu.com/docs/0J71/4.14
https://www.fa.omron.co.jp/product/item/SS-01GL13-E/

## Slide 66

配線を作る

WAGOへ電線を差し込む

01

本体のストリップ長表示に合わせて被覆をむき、芯線を傷付けない。

レバーを起こし、1つの穴へ1本だけ、銅線の先が止まるまで差す。

02

03

レバーを閉じ、銅線のはみ出しを見てから1本ずつ軽く引く。

確認：赤同士で1個、黒同士で1個。2つの穴は内部で導通している。

WAGO 221-412／WFR-2BP ×2 ／ XT60既設線・4942

最終更新日：2026年9月15日

66

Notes: WAGOへ電線を差し込む
WAGO 221-412／WFR-2BP ×2 ／ XT60既設線・4942
本体のストリップ長表示に合わせて被覆をむき、芯線を傷付けない。
レバーを起こし、1つの穴へ1本だけ、銅線の先が止まるまで差す。
レバーを閉じ、銅線のはみ出しを見てから1本ずつ軽く引く。
赤同士で1個、黒同士で1個。2つの穴は内部で導通している。
https://github.com/dainakai/plate-lift-control
https://www.pololu.com/product/3130/specs
https://www.pololu.com/docs/0J71/4.2
https://www.pololu.com/docs/0J71/4.14
https://www.fa.omron.co.jp/product/item/SS-01GL13-E/

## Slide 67

配線を作る

250型メス端子を圧着する

01

はじめに絶縁スリーブを電線へ通す。端子の指定に合わせて被覆をむく。

芯線の羽根と被覆の羽根を、対応する圧着工具でそれぞれ閉じる。

02

03

軽く引いて抜けないことを確認し、スリーブを端子へかぶせる。

確認：完成した2個をエーモン3214の2本の平端子へ奥まで差す。

エーモン3311：端子・スリーブ 各2 ／ 4942赤線

最終更新日：2026年9月15日

67

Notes: 250型メス端子を圧着する
エーモン3311：端子・スリーブ 各2 ／ 4942赤線
はじめに絶縁スリーブを電線へ通す。端子の指定に合わせて被覆をむく。
芯線の羽根と被覆の羽根を、対応する圧着工具でそれぞれ閉じる。
軽く引いて抜けないことを確認し、スリーブを端子へかぶせる。
完成した2個をエーモン3214の2本の平端子へ奥まで差す。
https://github.com/dainakai/plate-lift-control
https://www.pololu.com/product/3130/specs
https://www.pololu.com/docs/0J71/4.2
https://www.pololu.com/docs/0J71/4.14
https://www.fa.omron.co.jp/product/item/SS-01GL13-E/

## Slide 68

配線を作る

はんだ端子を1本ずつ絶縁する

01

接続する電線へ、熱収縮チューブを先に通す。

線を端子へはんだ付けし、隣の端子との橋絡がないか見る。

02

03

冷めてからチューブを移し、露出した金属を覆って収縮させる。

確認：SS-01GL13-Eは必要ならねじを外して配線し、元の向きへ戻す。

エーモン1196 ／ KIT-NR312・SS-01GL13-E

最終更新日：2026年9月15日

68

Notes: はんだ端子を1本ずつ絶縁する
エーモン1196 ／ KIT-NR312・SS-01GL13-E
接続する電線へ、熱収縮チューブを先に通す。
線を端子へはんだ付けし、隣の端子との橋絡がないか見る。
冷めてからチューブを移し、露出した金属を覆って収縮させる。
SS-01GL13-Eは必要ならねじを外して配線し、元の向きへ戻す。
https://github.com/dainakai/plate-lift-control
https://www.pololu.com/product/3130/specs
https://www.pololu.com/docs/0J71/4.2
https://www.pololu.com/docs/0J71/4.14
https://www.fa.omron.co.jp/product/item/SS-01GL13-E/

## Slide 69

配線を作る

電線は仮配線してから切る

01

必要分を赤と黒へ裂き、行き先の名前を両端に付ける。

箱を開けたまま部品間へ沿わせ、端末処理分と取り外す余裕を残す。

02

03

ふたを仮に置いて挟まれない長さを決め、切断する。

確認：側板を外せる余長を残す。配線の切断長は現物で決める。

エーモン4942：0.50 sq赤黒ダブルコード

最終更新日：2026年9月15日

69

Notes: 電線は仮配線してから切る
エーモン4942：0.50 sq赤黒ダブルコード
必要分を赤と黒へ裂き、行き先の名前を両端に付ける。
箱を開けたまま部品間へ沿わせ、端末処理分と取り外す余裕を残す。
ふたを仮に置いて挟まれない長さを決め、切断する。
側板を外せる余長を残す。配線の切断長は現物で決める。
https://github.com/dainakai/plate-lift-control
https://www.pololu.com/product/3130/specs
https://www.pololu.com/docs/0J71/4.2
https://www.pololu.com/docs/0J71/4.14
https://www.fa.omron.co.jp/product/item/SS-01GL13-E/

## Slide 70

配線を作る

DC電源の接続を1本ずつ追う

電源の赤バナナ
DC＋（24 V以下）

→

XT60オス → メス
パネル電源口

→

WAGO 正極用
太い線 → 0.50 sq

↓

Tic T825
VIN

主電源3214
250型メス端子×2

KIT-NR312
内部に2 Aヒューズ

←

←

黒バナナ → XT60 → WAGO 0 V用 → Tic GND

0 V

PCのUSB-A ── U2C-AMB10BK ── TicのMicro-B（通信）

電源は24 V以下。21.2 Vで使用可。配線作業は出力OFF・USBも外す。

最終更新日：2026年9月15日

70

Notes: DC電源の接続を1本ずつ追う
電源は24 V以下。21.2 Vで使用可。配線作業は出力OFF・USBも外す。
https://github.com/dainakai/plate-lift-control
https://www.pololu.com/product/3130/specs
https://www.pololu.com/docs/0J71/4.2
https://www.pololu.com/docs/0J71/4.14
https://www.fa.omron.co.jp/product/item/SS-01GL13-E/

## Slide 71

配線を作る

スイッチのCOMとNCを確認

下端 SS-01GL13-E

COM

NC

黒線 → TicのGNDピン

信号線 → SCL（reverse）

上端 SS-01GL13-E

COM

NC

黒線 → TicのGNDピン

信号線 → SDA（forward）

レバーを離す：COM–NC 導通　／　押す：COM–NC 開路

端子の左右順で決めない。刻印と導通を照合。使わないNOは無接続。

最終更新日：2026年9月15日

71

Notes: スイッチのCOMとNCを確認
端子の左右順で決めない。刻印と導通を照合。使わないNOは無接続。
https://github.com/dainakai/plate-lift-control
https://www.pololu.com/product/3130/specs
https://www.pololu.com/docs/0J71/4.2
https://www.pololu.com/docs/0J71/4.14
https://www.fa.omron.co.jp/product/item/SS-01GL13-E/

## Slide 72

配線を作る

基板上のどの端子へ接続するか

01

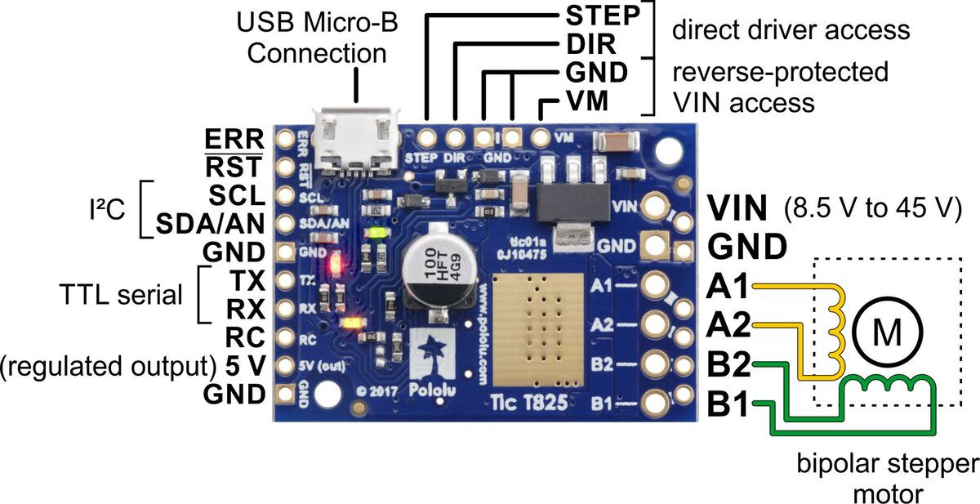
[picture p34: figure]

図ではMicro-Bが上。左の細いピン列が信号用、右が電源・モーター用。

左列をUSB寄りから数えて3番がSCL、4番がSDA/AN。

02

03

左列5番と10番がGND。上下のCOMを1本ずつ接続する。

確認：5 V・VM・VINとGNDを取り違えない。実物の印字も照合。

Pololu公式ピン配置図（部品面から見る）

最終更新日：2026年9月15日

72

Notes: 基板上のどの端子へ接続するか
Pololu公式ピン配置図（部品面から見る）
図ではMicro-Bが上。左の細いピン列が信号用、右が電源・モーター用。
左列をUSB寄りから数えて3番がSCL、4番がSDA/AN。
左列5番と10番がGND。上下のCOMを1本ずつ接続する。
5 V・VM・VINとGNDを取り違えない。実物の印字も照合。
https://github.com/dainakai/plate-lift-control
https://www.pololu.com/product/3130/specs
https://www.pololu.com/docs/0J71/4.2
https://www.pololu.com/docs/0J71/4.14
https://www.fa.omron.co.jp/product/item/SS-01GL13-E/

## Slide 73

配線を作る

信号ピンにはメス端子付き線を使う

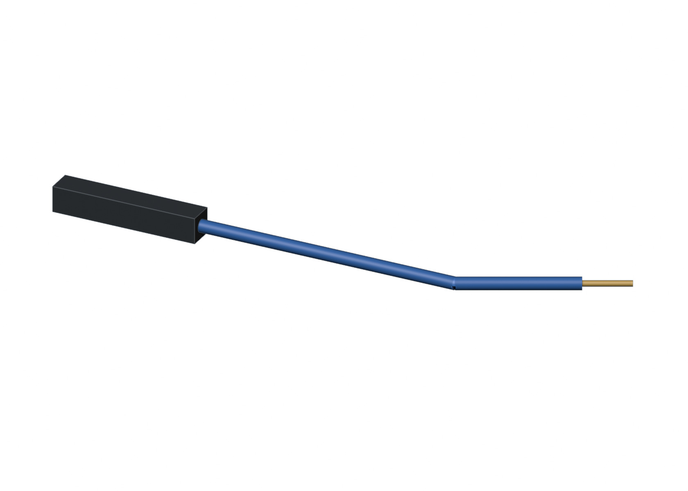
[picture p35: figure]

01

SCL、SDA/AN、2つのGNDへ、1ピンのメス端子を1本ずつ差す。

反対端をスイッチ線へはんだ接続し、接続部を熱収縮チューブで覆う。

02

03

コネクタの根元を固定側へ留め、68 mm往復でも抜けないか確認する。

確認：この4本は旧購入表に未記載。手元にない場合は追加してから配線する。

2.54 mm・1ピンのメス端子付きリード線 ×4（手持ち確認）

最終更新日：2026年9月15日

73

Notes: 信号ピンにはメス端子付き線を使う
2.54 mm・1ピンのメス端子付きリード線 ×4（手持ち確認）
SCL、SDA/AN、2つのGNDへ、1ピンのメス端子を1本ずつ差す。
反対端をスイッチ線へはんだ接続し、接続部を熱収縮チューブで覆う。
コネクタの根元を固定側へ留め、68 mm往復でも抜けないか確認する。
この4本は旧購入表に未記載。手元にない場合は追加してから配線する。
https://github.com/dainakai/plate-lift-control
https://www.pololu.com/product/3130/specs
https://www.pololu.com/docs/0J71/4.2
https://www.pololu.com/docs/0J71/4.14
https://www.fa.omron.co.jp/product/item/SS-01GL13-E/

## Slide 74

配線を作る

Ticへ入れる線の接続表

接続元 | Ticに印字された端子 | 役割
主電源スイッチを通った赤線 | VIN | モーター用DC電源
0 V用WAGOの黒線 | GND（電源側） | 電源の戻り
下側スイッチのNC | SCL | reverse limit：下向きを禁止
上側スイッチのNC | SDA | forward limit：上向きを禁止
上下スイッチのCOM | GND（信号側） | 入力の0 V基準

SCL・SDA・信号GNDは信号端子。そこへモーター用DC電源を入れない。

最終更新日：2026年9月15日

74

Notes: Ticへ入れる線の接続表
SCL・SDA・信号GNDは信号端子。そこへモーター用DC電源を入れない。
https://github.com/dainakai/plate-lift-control
https://www.pololu.com/product/3130/specs
https://www.pololu.com/docs/0J71/4.2
https://www.pololu.com/docs/0J71/4.14
https://www.fa.omron.co.jp/product/item/SS-01GL13-E/

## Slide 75

配線を作る

モーターの2つのコイルをつなぐ

01

モーターを外した状態で、抵抗がある2本の組をテスターで探す。

一方の組をA1/A2へ、もう一方の組をB1/B2へ接続する。

02

03

ねじ端子から銅線がはみ出さず、引いても抜けないことを確認する。

確認：線色は決め打ちしない。励磁中に端子を抜き差ししない。

C-42STM01の4本線 → Tic T825

最終更新日：2026年9月15日

75

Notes: モーターの2つのコイルをつなぐ
C-42STM01の4本線 → Tic T825
モーターを外した状態で、抵抗がある2本の組をテスターで探す。
一方の組をA1/A2へ、もう一方の組をB1/B2へ接続する。
ねじ端子から銅線がはみ出さず、引いても抜けないことを確認する。
線色は決め打ちしない。励磁中に端子を抜き差ししない。
https://github.com/dainakai/plate-lift-control
https://www.pololu.com/product/3130/specs
https://www.pololu.com/docs/0J71/4.2
https://www.pololu.com/docs/0J71/4.14
https://www.fa.omron.co.jp/product/item/SS-01GL13-E/

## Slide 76

配線を作る

電源ケーブルを外からつなぐ

01

赤バナナを安定化電源の＋、黒バナナを0 Vへ対応させる。

出力OFFで極性を確認し、電圧を24 V以下に設定する。21.2 Vでも使える。

02

03

XT60オスを装置のパネルメスへ、形と極性を合わせて差す。

確認：2本組のうち1本を使用。装置の主電源はまだOFF。

Yiqigou XT60オス–4 mmバナナケーブル

最終更新日：2026年9月15日

76

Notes: 電源ケーブルを外からつなぐ
Yiqigou XT60オス–4 mmバナナケーブル
赤バナナを安定化電源の＋、黒バナナを0 Vへ対応させる。
出力OFFで極性を確認し、電圧を24 V以下に設定する。21.2 Vでも使える。
XT60オスを装置のパネルメスへ、形と極性を合わせて差す。
2本組のうち1本を使用。装置の主電源はまだOFF。
https://github.com/dainakai/plate-lift-control
https://www.pololu.com/product/3130/specs
https://www.pololu.com/docs/0J71/4.2
https://www.pololu.com/docs/0J71/4.14
https://www.fa.omron.co.jp/product/item/SS-01GL13-E/

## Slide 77

電子箱を組み立てる

駆動側板の中央へ配線を通す

01

モーター線と上下リミットの線を、中央の角穴へ通す。

コネクタや端末を接続する前に通し、箱内でTicへつなぐ。

02

03

固定フレーム側へ束ね、68 mm全域で可動部やレバーへ触れないようにする。

確認：Ticは底板に固定する。配線口の角に線が強く当たらないこと。

駆動側板の配線口：41×16 mm

最終更新日：2026年9月15日

77

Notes: 駆動側板の中央へ配線を通す
駆動側板の配線口：41×16 mm
モーター線と上下リミットの線を、中央の角穴へ通す。
コネクタや端末を接続する前に通し、箱内でTicへつなぐ。
固定フレーム側へ束ね、68 mm全域で可動部やレバーへ触れないようにする。
Ticは底板に固定する。配線口の角に線が強く当たらないこと。
https://github.com/dainakai/plate-lift-control
https://www.pololu.com/product/3130/specs
https://www.pololu.com/docs/0J71/4.2
https://www.pololu.com/docs/0J71/4.14
https://www.fa.omron.co.jp/product/item/SS-01GL13-E/

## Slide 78

電子箱を組み立てる

ヒューズ側板を4本で固定する

01

側板を開けたまま端子を配線・絶縁し、余長を箱内へ収める。

ヒューズ側板の四隅からM3×8を入れ、USB側板と駆動側板へ留める。

02

03

下の2個のインサートはベース固定用なので、ここでは使わない。

確認：板を合わせたとき、裏の取付ナット・端子・線が柱に当たらない。

M3×8 ×4

最終更新日：2026年9月15日

78

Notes: ヒューズ側板を4本で固定する
M3×8 ×4
側板を開けたまま端子を配線・絶縁し、余長を箱内へ収める。
ヒューズ側板の四隅からM3×8を入れ、USB側板と駆動側板へ留める。
下の2個のインサートはベース固定用なので、ここでは使わない。
板を合わせたとき、裏の取付ナット・端子・線が柱に当たらない。
https://github.com/dainakai/plate-lift-control
https://www.pololu.com/product/3130/specs
https://www.pololu.com/docs/0J71/4.2
https://www.pololu.com/docs/0J71/4.14
https://www.fa.omron.co.jp/product/item/SS-01GL13-E/

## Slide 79

電子箱を組み立てる

電源側板を4本で固定する

01

XT60と主電源の配線を確認し、露出した端子を絶縁する。

電源側板を合わせ、四隅のM3×8を両側板のインサートへ留める。

02

03

XT60の太い線を急に曲げず、天板のねじ受けから離して収める。

確認：側板を工具で無理に押し込まない。締める前に挟み込みを確認する。

M3×8 ×4

最終更新日：2026年9月15日

79

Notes: 電源側板を4本で固定する
M3×8 ×4
XT60と主電源の配線を確認し、露出した端子を絶縁する。
電源側板を合わせ、四隅のM3×8を両側板のインサートへ留める。
XT60の太い線を急に曲げず、天板のねじ受けから離して収める。
側板を工具で無理に押し込まない。締める前に挟み込みを確認する。
https://github.com/dainakai/plate-lift-control
https://www.pololu.com/product/3130/specs
https://www.pololu.com/docs/0J71/4.2
https://www.pololu.com/docs/0J71/4.14
https://www.fa.omron.co.jp/product/item/SS-01GL13-E/

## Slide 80

電子箱を組み立てる

天板を4本で固定する

01

通気穴のある天板を、4枚の側板の上へまっすぐ載せる。

四隅の凹みからM3×8を入れ、USB側板と駆動側板の上端へ留める。

02

03

対角の順に少しずつ締め、ねじ頭を凹みへ収める。

確認：置くだけのふたではない。線を挟まず、4本で固定する。

天板 ／ M3×8 ×4

最終更新日：2026年9月15日

80

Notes: 天板を4本で固定する
天板 ／ M3×8 ×4
通気穴のある天板を、4枚の側板の上へまっすぐ載せる。
四隅の凹みからM3×8を入れ、USB側板と駆動側板の上端へ留める。
対角の順に少しずつ締め、ねじ頭を凹みへ収める。
置くだけのふたではない。線を挟まず、4本で固定する。
https://github.com/dainakai/plate-lift-control
https://www.pololu.com/product/3130/specs
https://www.pololu.com/docs/0J71/4.2
https://www.pololu.com/docs/0J71/4.14
https://www.fa.omron.co.jp/product/item/SS-01GL13-E/

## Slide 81

電子箱を組み立てる

組んだ電子箱をベースへ固定する

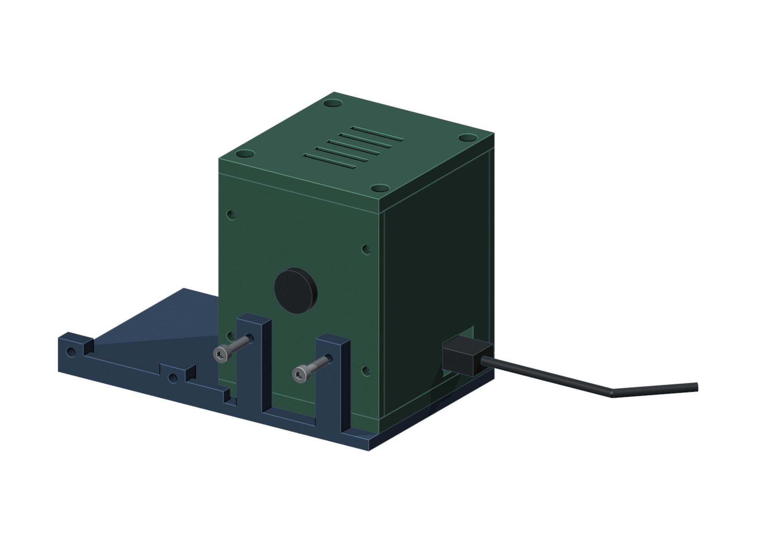
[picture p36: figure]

01

USB側板をベースの外端に合わせ、底板をベースへ載せる。

ベースの側面2穴からM3×12を通し、ヒューズ側板のインサートへ締める。

02

03

USB側がはみ出さず、フレーム側の配線口に余裕があることを確認する。

確認：USBプラグの後方には約70 mmの配線スペースを取る。

M3×12 ×2（ベース側から）

最終更新日：2026年9月15日

81

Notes: 組んだ電子箱をベースへ固定する
M3×12 ×2（ベース側から）
USB側板をベースの外端に合わせ、底板をベースへ載せる。
ベースの側面2穴からM3×12を通し、ヒューズ側板のインサートへ締める。
USB側がはみ出さず、フレーム側の配線口に余裕があることを確認する。
USBプラグの後方には約70 mmの配線スペースを取る。
https://github.com/dainakai/plate-lift-control
https://www.pololu.com/product/3130/specs
https://www.pololu.com/docs/0J71/4.2
https://www.pololu.com/docs/0J71/4.14
https://www.fa.omron.co.jp/product/item/SS-01GL13-E/

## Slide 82

試験片を試す

試験片の名前と採用寸法

試験片 | 採用寸法
XT60取付試験片 | 最小：20.2×12.2 mm
ヒューズホルダー試験片 | 最大：φ13.0 mm
主電源スイッチ試験片 | 最大：φ12.4 mm
軸受試験片 | 最大：φ15.5 mm（暫定）
M3インサート試験片 | 中央：φ4.2 mm
ガラス溝試験片 | 中央：2.9 mm

材料や印刷条件を変えたときに確認する。付属の試験片ZIPは別ファイル。

最終更新日：2026年9月15日

82

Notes: 試験片の名前と採用寸法
材料や印刷条件を変えたときに確認する。付属の試験片ZIPは別ファイル。
https://github.com/dainakai/plate-lift-control
https://www.pololu.com/product/3130/specs
https://www.pololu.com/docs/0J71/4.2
https://www.pololu.com/docs/0J71/4.14
https://www.fa.omron.co.jp/product/item/SS-01GL13-E/

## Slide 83

試験片を試す

XT60はナットまで付けて試す

01

最小の20.2×12.2開口へ、既設線から通して胴を入れる。

フランジを密着させ、左右のM2ねじとナットで仮固定する。

02

03

相手のXT60オスを挿し、がた・割れ・ナットと胴の干渉を見る。

確認：採用済み：最小。無理な圧入と穴を削っての合格は記録を分ける。

XT60取付試験片 ／ XT60E-F ／ M2×8・M2ナット 各2

最終更新日：2026年9月15日

83

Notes: XT60はナットまで付けて試す
XT60取付試験片 ／ XT60E-F ／ M2×8・M2ナット 各2
最小の20.2×12.2開口へ、既設線から通して胴を入れる。
フランジを密着させ、左右のM2ねじとナットで仮固定する。
相手のXT60オスを挿し、がた・割れ・ナットと胴の干渉を見る。
採用済み：最小。無理な圧入と穴を削っての合格は記録を分ける。
https://github.com/dainakai/plate-lift-control
https://www.pololu.com/product/3130/specs
https://www.pololu.com/docs/0J71/4.2
https://www.pololu.com/docs/0J71/4.14
https://www.fa.omron.co.jp/product/item/SS-01GL13-E/

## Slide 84

試験片を試す

丸穴は「板を挟める」まで試す

ヒューズ：最大φ13.0 mm

主電源：最大φ12.4 mm

胴を通す → 付属ナットで板を挟む → 手で操作して回らない・割れないことを確認。

最終更新日：2026年9月15日

84

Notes: 丸穴は「板を挟める」まで試す
胴を通す → 付属ナットで板を挟む → 手で操作して回らない・割れないことを確認。
https://github.com/dainakai/plate-lift-control
https://www.pololu.com/product/3130/specs
https://www.pololu.com/docs/0J71/4.2
https://www.pololu.com/docs/0J71/4.14
https://www.fa.omron.co.jp/product/item/SS-01GL13-E/

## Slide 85

試験片を試す

軸受は押さえと組にして判断

01

φ15.5の座へ、軸受を水平に指で挿入する。

傾き・横がたを調べ、内輪が軽く回ることを確認する。

02

03

本体では軸受押さえも装着し、軸方向の抜けを確認する。

確認：穴径は暫定採用。現物で回転・がた・軸方向の抜けを確認する。

軸受試験片 ／ 696ZZ

最終更新日：2026年9月15日

85

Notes: 軸受は押さえと組にして判断
軸受試験片 ／ 696ZZ
φ15.5の座へ、軸受を水平に指で挿入する。
傾き・横がたを調べ、内輪が軽く回ることを確認する。
本体では軸受押さえも装着し、軸方向の抜けを確認する。
穴径は暫定採用。現物で回転・がた・軸方向の抜けを確認する。
https://github.com/dainakai/plate-lift-control
https://www.pololu.com/product/3130/specs
https://www.pololu.com/docs/0J71/4.2
https://www.pololu.com/docs/0J71/4.14
https://www.fa.omron.co.jp/product/item/SS-01GL13-E/

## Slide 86

試験片を試す

インサートは冷えてから試す

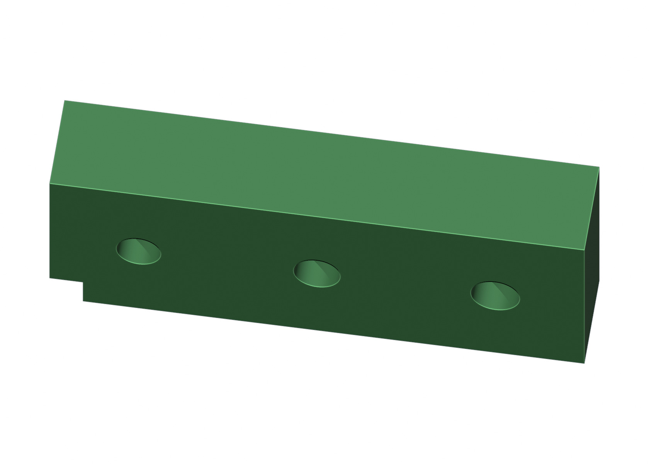
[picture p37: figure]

01

本体と同じ材料・積層・穴の向きで試験片を作る。

こてを軸に合わせて入れ、インサートが面とそろう位置で止める。

02

03

室温まで冷やし、M3×4と座金で軽く留めて空回りを調べる。

確認：長いねじの底付きは「固定できた」ことにならない。

M3インサート試験片 ／ 中央φ4.2

最終更新日：2026年9月15日

86

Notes: インサートは冷えてから試す
M3インサート試験片 ／ 中央φ4.2
本体と同じ材料・積層・穴の向きで試験片を作る。
こてを軸に合わせて入れ、インサートが面とそろう位置で止める。
室温まで冷やし、M3×4と座金で軽く留めて空回りを調べる。
長いねじの底付きは「固定できた」ことにならない。
https://github.com/dainakai/plate-lift-control
https://www.pololu.com/product/3130/specs
https://www.pololu.com/docs/0J71/4.2
https://www.pololu.com/docs/0J71/4.14
https://www.fa.omron.co.jp/product/item/SS-01GL13-E/

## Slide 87

試験片を試す

ガラス溝は保持と抜き差しを試す

01

中央の本体と前枠を組み、支持ねじも実際に付ける。

同じ厚さ2.3 mmの板を上から入れ、5 mmの掛かりを確認。

02

03

引っ掛かり・前後のがた・支持ねじの固定・枠の割れを見る。

確認：採用済み：中央2.9 mm。ガラスを締め潰して保持しない。

ガラス溝試験片：中央2.9 mm ／ USLL6・ナット

最終更新日：2026年9月15日

87

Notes: ガラス溝は保持と抜き差しを試す
ガラス溝試験片：中央2.9 mm ／ USLL6・ナット
中央の本体と前枠を組み、支持ねじも実際に付ける。
同じ厚さ2.3 mmの板を上から入れ、5 mmの掛かりを確認。
引っ掛かり・前後のがた・支持ねじの固定・枠の割れを見る。
採用済み：中央2.9 mm。ガラスを締め潰して保持しない。
https://github.com/dainakai/plate-lift-control
https://www.pololu.com/product/3130/specs
https://www.pololu.com/docs/0J71/4.2
https://www.pololu.com/docs/0J71/4.14
https://www.fa.omron.co.jp/product/item/SS-01GL13-E/

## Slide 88

Adventurer 5M Pro

フレームとキャリアの印刷姿勢

駆動フレーム：背面を下にする

キャリア3部品：それぞれ平らな面を下に

0.4 mmノズル、0.2 mm積層を開始値とし、試験片と同じ穴補正で印刷する。

最終更新日：2026年9月15日

88

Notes: フレームとキャリアの印刷姿勢
0.4 mmノズル、0.2 mm積層を開始値とし、試験片と同じ穴補正で印刷する。
https://github.com/dainakai/plate-lift-control
https://www.pololu.com/product/3130/specs
https://www.pololu.com/docs/0J71/4.2
https://www.pololu.com/docs/0J71/4.14
https://www.fa.omron.co.jp/product/item/SS-01GL13-E/

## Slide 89

Adventurer 5M Pro

電子箱は各板の平らな外面を下に印刷

USB・駆動・ヒューズ側板：内側が上

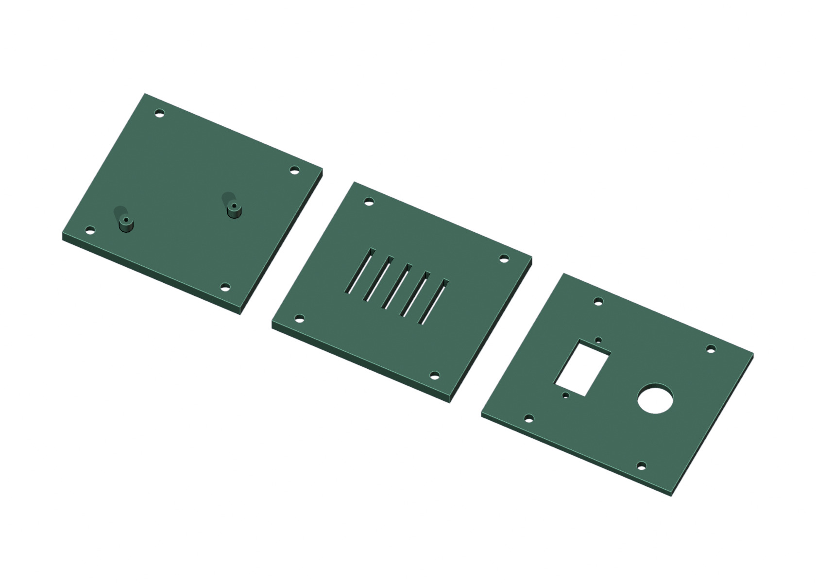
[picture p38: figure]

底板・天板・電源側板：凹みと穴を確認

STLはこの向きで収録。各部品を個別に配置し、ねじ穴の小さなブリッジはスライサーで確認。

最終更新日：2026年9月15日

89

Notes: 電子箱は各板の平らな外面を下に印刷
STLはこの向きで収録。各部品を個別に配置し、ねじ穴の小さなブリッジはスライサーで確認。
https://github.com/dainakai/plate-lift-control
https://www.pololu.com/product/3130/specs
https://www.pololu.com/docs/0J71/4.2
https://www.pololu.com/docs/0J71/4.14
https://www.fa.omron.co.jp/product/item/SS-01GL13-E/

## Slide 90

Adventurer 5M Pro

印刷後に開口を目で確認

場所 | 印刷後の確認
駆動フレーム | U字挿入口、蓋の凹み、軸受座と固定穴が開いている
キャリア3部品 | M2の段付き穴、M4の4穴、M3穴・インサート穴を照合
電子箱の6枚 | USB・配線口・Ticのφ1.6下穴・四隅の穴と頭の凹みを確認
M3インサート穴 | 指定した26穴を確認。穴底を貫通させない
ホルダー本体・前枠 | 溝とねじ位置の糸引き、支持ねじの座を確認
パネル・軸受押さえ | 穴の薄膜を除き、ねじが指定方向から入る

試験片と同じ材料・造形条件で確認する。STLの単位はmm、倍率は100%。

最終更新日：2026年9月15日

90

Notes: 印刷後に開口を目で確認
試験片と同じ材料・造形条件で確認する。STLの単位はmm、倍率は100%。
https://github.com/dainakai/plate-lift-control
https://www.pololu.com/product/3130/specs
https://www.pololu.com/docs/0J71/4.2
https://www.pololu.com/docs/0J71/4.14
https://www.fa.omron.co.jp/product/item/SS-01GL13-E/

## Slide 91

リミットと高さを調整する

下端は「戻った位置」で合わせる

01

無通電でキャリアを下げ、COM–NCが開く位置を確かめる。

少し上へ戻し、COM–NCが再び閉じる位置で高さを測る。

02

03

そこで板の下面が17 mmとなるよう、下側スイッチを長穴で動かす。

確認：押す位置と戻る位置は異なる。機械ストップへ押し付けて原点にしない。

テスター ／ 高さを測る定規・ノギス ／ ダミー板

最終更新日：2026年9月15日

91

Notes: 下端は「戻った位置」で合わせる
テスター ／ 高さを測る定規・ノギス ／ ダミー板
無通電でキャリアを下げ、COM–NCが開く位置を確かめる。
少し上へ戻し、COM–NCが再び閉じる位置で高さを測る。
そこで板の下面が17 mmとなるよう、下側スイッチを長穴で動かす。
押す位置と戻る位置は異なる。機械ストップへ押し付けて原点にしない。
https://github.com/dainakai/plate-lift-control
https://www.pololu.com/product/3130/specs
https://www.pololu.com/docs/0J71/4.2
https://www.pololu.com/docs/0J71/4.14
https://www.fa.omron.co.jp/product/item/SS-01GL13-E/

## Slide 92

リミットと高さを調整する

上端の復帰高さを85 mmへ合わせる

01

キャリアを上げ、上側スイッチのCOM–NCが開く位置を探す。

少し下へ戻し、再び閉じる位置で板の下面が85 mmか測る。

02

03

上側スイッチを長穴で動かし、下端との差を68 mmへ合わせる。

確認：両端とも、復帰端点から約1 mm先に機械ストップ。

上端SS-01GL13-E ／ テスター・高さ測定

最終更新日：2026年9月15日

92

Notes: 上端の復帰高さを85 mmへ合わせる
上端SS-01GL13-E ／ テスター・高さ測定
キャリアを上げ、上側スイッチのCOM–NCが開く位置を探す。
少し下へ戻し、再び閉じる位置で板の下面が85 mmか測る。
上側スイッチを長穴で動かし、下端との差を68 mmへ合わせる。
両端とも、復帰端点から約1 mm先に機械ストップ。
https://github.com/dainakai/plate-lift-control
https://www.pololu.com/product/3130/specs
https://www.pololu.com/docs/0J71/4.2
https://www.pololu.com/docs/0J71/4.14
https://www.fa.omron.co.jp/product/item/SS-01GL13-E/

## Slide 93

リミットと高さを調整する

機械ストップはガイドブロックへ当てる

下端：ブロック下面と軸受座の内側

上端：ブロック上面と背板内側の突起

図はブロックを5 mm離した表示。実機のストップは復帰点から上下1 mm先。

最終更新日：2026年9月15日

93

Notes: 機械ストップはガイドブロックへ当てる
図はブロックを5 mm離した表示。実機のストップは復帰点から上下1 mm先。
https://github.com/dainakai/plate-lift-control
https://www.pololu.com/product/3130/specs
https://www.pololu.com/docs/0J71/4.2
https://www.pololu.com/docs/0J71/4.14
https://www.fa.omron.co.jp/product/item/SS-01GL13-E/

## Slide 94

組立完了チェックリスト

無通電の仮組みチェック

対象 | 確認
手回し68 mm | 引っ掛かり、軸の振れ、ナットの斜め入りがない
上下スイッチ | 取付板がレバーを先に押し、その後にガイドブロックがストップへ当たる
下端の台との隙間 | ストップ時のUSLL6ねじ先と台：公称1.5 mm。現物で1 mm以上
ガラス保持 | 支持3点、前後の溝、端の掛かり5 mm、枠の割れなし
電装・工具 | ねじを締められる。端子に金属露出なし。ふたが線を挟まない

CADの干渉検査は実機試験の代わりにならない。台が傾く・たわむ場合も測り直す。

最終更新日：2026年9月15日

94

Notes: 無通電の仮組みチェック
CADの干渉検査は実機試験の代わりにならない。台が傾く・たわむ場合も測り直す。
https://github.com/dainakai/plate-lift-control
https://www.pololu.com/product/3130/specs
https://www.pololu.com/docs/0J71/4.2
https://www.pololu.com/docs/0J71/4.14
https://www.fa.omron.co.jp/product/item/SS-01GL13-E/

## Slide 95

初回通電する

初回通電する前のチェック

確認するもの | 条件
極性 | XT60の＋→ヒューズ→主電源→VIN、0 V→GND
短絡 | VINとGND、隣接端子、線の飛び出しを点検
ヒューズ | 5.2×20 mm、2 Aを装着
モーター | コイル対を測定済み。A1/A2とB1/B2に正しく接続
ガラス | 実ガラスを入れず、配線変更前はDC電源とUSBを外す

DC電源は24 V以下に設定。使用中の直流安定化電源の21.2 Vで動作確認済み。

最終更新日：2026年9月15日

95

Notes: 初回通電する前のチェック
DC電源は24 V以下に設定。使用中の直流安定化電源の21.2 Vで動作確認済み。
https://github.com/dainakai/plate-lift-control
https://www.pololu.com/product/3130/specs
https://www.pololu.com/docs/0J71/4.2
https://www.pololu.com/docs/0J71/4.14
https://www.fa.omron.co.jp/product/item/SS-01GL13-E/

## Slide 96

パソコンの準備

Mac：Ticソフトとuvを準備する

順番 | 操作
Ticソフト | Pololu公式のmacOS手順でTicソフトをインストール
uv | ターミナルで次のインストールコマンドを実行
コマンド | curl -LsSf https://astral.sh/uv/install.sh | sh
反映 | ターミナルを開き直す
入っていれば | Ticソフトとuvの再インストールは不要

リンクとコピー用コマンドはGitHubのREADMEに掲載。

最終更新日：2026年9月15日

96

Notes: Mac：Ticソフトとuvを準備する
リンクとコピー用コマンドはGitHubのREADMEに掲載。
https://github.com/dainakai/plate-lift-control
https://www.pololu.com/product/3130/specs
https://www.pololu.com/docs/0J71/4.2
https://www.pololu.com/docs/0J71/4.14
https://www.fa.omron.co.jp/product/item/SS-01GL13-E/

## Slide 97

パソコンの準備

Windows：Ticソフトとuvを準備する

順番 | 操作
Ticソフト | Pololu公式のWindows手順でドライバーを含めてインストール
uv | PowerShellで次のコマンドを実行
コマンド | winget install --id=astral-sh.uv -e
反映 | PowerShellを開き直す
入っていれば | Ticソフトとuvの再インストールは不要

wingetが使えない場合は、README内のuv公式インストール手順へ。

最終更新日：2026年9月15日

97

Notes: Windows：Ticソフトとuvを準備する
wingetが使えない場合は、README内のuv公式インストール手順へ。
https://github.com/dainakai/plate-lift-control
https://www.pololu.com/product/3130/specs
https://www.pololu.com/docs/0J71/4.2
https://www.pololu.com/docs/0J71/4.14
https://www.fa.omron.co.jp/product/item/SS-01GL13-E/

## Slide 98

パソコンの準備

スクリプトをダウンロードして準備する

順番 | 操作
ダウンロード | GitHubのCode → Download ZIPから入手して展開
保存先 | ダウンロード内のplate-lift-control-mainを使う
Macで移動 | cd ~/Downloads/plate-lift-control-main
Windowsで移動 | cd "$env:USERPROFILE\Downloads\plate-lift-control-main"
共通の準備 | uv sync

Pythonはuvが用意する。初回の準備はインターネット接続が必要。

最終更新日：2026年9月15日

98

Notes: スクリプトをダウンロードして準備する
Pythonはuvが用意する。初回の準備はインターネット接続が必要。
https://github.com/dainakai/plate-lift-control
https://www.pololu.com/product/3130/specs
https://www.pololu.com/docs/0J71/4.2
https://www.pololu.com/docs/0J71/4.14
https://www.fa.omron.co.jp/product/item/SS-01GL13-E/

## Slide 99

必要なときの設定

Ticを交換・初期化したときだけ設定する

対象 | 操作・設定
使用中の設定済みTic | この設定作業は不要。up／downを実行する
新品・初期化後 | GitHubのdocs/tic-setup.mdの手順で設定ファイルを適用
下端SCL | reverse limit、Pull-up有効、Active high
上端SDA | forward limit、Pull-up有効、Active high
適用後 | ガラスなしで向きと上下の停止入力を確認

毎回のApply settingsは不要。スクリプトは保存済みの電流制限とリミット設定を使う。

最終更新日：2026年9月15日

99

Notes: Ticを交換・初期化したときだけ設定する
毎回のApply settingsは不要。スクリプトは保存済みの電流制限とリミット設定を使う。
https://github.com/dainakai/plate-lift-control
https://www.pololu.com/product/3130/specs
https://www.pololu.com/docs/0J71/4.2
https://www.pololu.com/docs/0J71/4.14
https://www.fa.omron.co.jp/product/item/SS-01GL13-E/

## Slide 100

USBと停止入力の確認

USBだけでリミット入力を試す

実物で行う操作 | Ticの表示
両スイッチを離す | forward/reverseともinactive
下側だけを押す | reverseだけactive
上側だけを押す | forwardだけactive
各NC線を1本ずつ外す | 対応する入力がactive
信号をGNDへ短絡した場合 | NC方式でも検出できない。短絡を残さない

USBを外してから線を変更し、再接続して確認。作業後に正しい配線へ戻す。

最終更新日：2026年9月15日

100

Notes: USBだけでリミット入力を試す
USBを外してから線を変更し、再接続して確認。作業後に正しい配線へ戻す。
https://github.com/dainakai/plate-lift-control
https://www.pololu.com/product/3130/specs
https://www.pololu.com/docs/0J71/4.2
https://www.pololu.com/docs/0J71/4.14
https://www.fa.omron.co.jp/product/item/SS-01GL13-E/

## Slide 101

動作を確認する

ガラスなしで初めて動かす

段階 | 操作と判定
接続 | USBとDC電源を接続し、Tic Control Centerを閉じる
下向き | uv run platectl home：下へ進むことを確認
端点 | 下端で止まり、少し戻って無励磁になる
上向き | uv run platectl up：上端で止まり、少し戻る
向きが逆 | 電源を外し、docs/tic-setup.mdの方向設定を確認

最初の位置不明時は端点を探すため、通常移動より時間が掛かる。

最終更新日：2026年9月15日

101

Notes: ガラスなしで初めて動かす
最初の位置不明時は端点を探すため、通常移動より時間が掛かる。
https://github.com/dainakai/plate-lift-control
https://www.pololu.com/product/3130/specs
https://www.pololu.com/docs/0J71/4.2
https://www.pololu.com/docs/0J71/4.14
https://www.fa.omron.co.jp/product/item/SS-01GL13-E/

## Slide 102

動作を確認する

ダミー板で保持と動きを試す

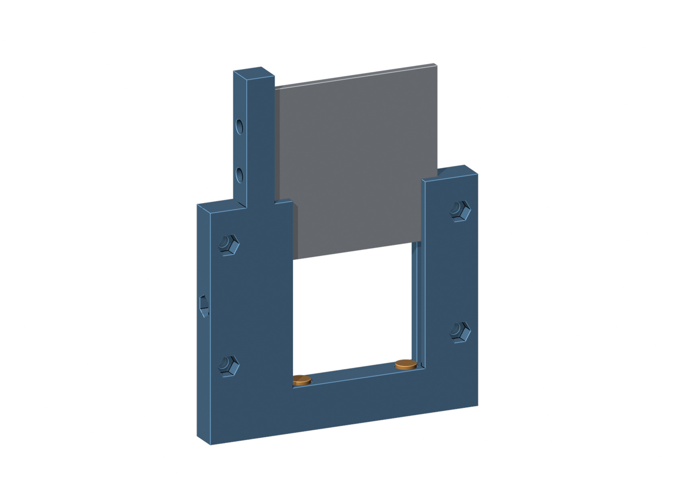
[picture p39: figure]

01

無励磁のDOWNで、板を上から左右の溝へ静かに差す。

下面2点に載せ、側面USLL6を軽く当てる。

02

03

手回し → 低速10往復の順に、ずれ・接触・抜けを調べる。

確認：前後面をねじで挟まない。上から抜き差しできること。

50×50×2.3 mmのダミー板

最終更新日：2026年9月15日

102

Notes: ダミー板で保持と動きを試す
50×50×2.3 mmのダミー板
無励磁のDOWNで、板を上から左右の溝へ静かに差す。
下面2点に載せ、側面USLL6を軽く当てる。
手回し → 低速10往復の順に、ずれ・接触・抜けを調べる。
前後面をねじで挟まない。上から抜き差しできること。
https://github.com/dainakai/plate-lift-control
https://www.pololu.com/product/3130/specs
https://www.pololu.com/docs/0J71/4.2
https://www.pololu.com/docs/0J71/4.14
https://www.fa.omron.co.jp/product/item/SS-01GL13-E/

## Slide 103

動作を確認する

実ガラスを入れて位置を確認

01

ダミー試験を終え、ガラスの縁に欠けがないことを確認する。

ドット面をカメラへ向け、DOWNで上から入れる。

02

03

DOWN17 mm、UP85 mmと、チェンバーとの隙間を現物で測る。

確認：ガラスの全面が駆動フレームに隠れず、枠が撮影範囲を遮らないこと。

ランダムドットガラス 50×50×2.3 mm

最終更新日：2026年9月15日

103

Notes: 実ガラスを入れて位置を確認
ランダムドットガラス 50×50×2.3 mm
ダミー試験を終え、ガラスの縁に欠けがないことを確認する。
ドット面をカメラへ向け、DOWNで上から入れる。
DOWN17 mm、UP85 mmと、チェンバーとの隙間を現物で測る。
ガラスの全面が駆動フレームに隠れず、枠が撮影範囲を遮らないこと。
https://github.com/dainakai/plate-lift-control
https://www.pololu.com/product/3130/specs
https://www.pololu.com/docs/0J71/4.2
https://www.pololu.com/docs/0J71/4.14
https://www.fa.omron.co.jp/product/item/SS-01GL13-E/

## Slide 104

受入試験

組立後に記録する実機試験

項目 | 記録・合否の目安
端点 | DOWN17 mm／UP85 mm、繰返し時の差
繰返し | ダミー100往復で脱調・緩み・配線擦れなし
移動時間 | 通常の端点間移動は各10秒以内を目安に実測
保持 | 最大想定荷重で24時間、鉛直ずれ0.5 mm以下
電源断・再接続 | ダミーで落下を確認し、再投入で自走しない

未実施の試験を合格扱いにしない。日時・電源電圧・条件・結果を手元に記録する。

最終更新日：2026年9月15日

104

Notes: 組立後に記録する実機試験
未実施の試験を合格扱いにしない。日時・電源電圧・条件・結果を手元に記録する。
https://github.com/dainakai/plate-lift-control
https://www.pololu.com/product/3130/specs
https://www.pololu.com/docs/0J71/4.2
https://www.pololu.com/docs/0J71/4.14
https://www.fa.omron.co.jp/product/item/SS-01GL13-E/

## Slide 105

使い方

普段はupとdownだけ

コマンド | 使うとき
uv run platectl up | ガラスを上げる（下面85 mm）
uv run platectl down | ガラスを下げる（下面17 mm）
uv run platectl status | 接続・位置・停止状態を確認
uv run platectl home | 下端を探し直す
uv run platectl shutdown | DOWNへ戻し、無励磁にして終了

既定の移動量は68 mm。位置不明ならup／downが端点を探す。Apply settingsは不要。

最終更新日：2026年9月15日

105

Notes: 普段はupとdownだけ
既定の移動量は68 mm。位置不明ならup／downが端点を探す。Apply settingsは不要。
https://github.com/dainakai/plate-lift-control
https://www.pololu.com/product/3130/specs
https://www.pololu.com/docs/0J71/4.2
https://www.pololu.com/docs/0J71/4.14
https://www.fa.omron.co.jp/product/item/SS-01GL13-E/

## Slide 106

使い方

操作するときの接続と速度

項目 | 使用方法
USB | パソコンとTicのMicro-B端子をデータケーブルで接続
DC電源 | 24 V以下。直流安定化電源の21.2 Vでも使用可
Tic Control Center | スクリプトを使う前に閉じる
通常の速度 | 150000000＝14.06 mm/s。端点付近は速度を下げる
電源を外す | shutdownの完了を確認してから電源とUSBを外す

電源装置の表示電流と、Ticのモーター相電流設定は別の値。

最終更新日：2026年9月15日

106

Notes: 操作するときの接続と速度
電源装置の表示電流と、Ticのモーター相電流設定は別の値。
https://github.com/dainakai/plate-lift-control
https://www.pololu.com/product/3130/specs
https://www.pololu.com/docs/0J71/4.2
https://www.pololu.com/docs/0J71/4.14
https://www.fa.omron.co.jp/product/item/SS-01GL13-E/

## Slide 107

保守

交換・再調整のとき

部品 | 作業
ヒューズ | DC電源・USBを外す → 外側キャップ → 同じ2 Aへ交換
主電源スイッチ | 250端子を抜く → 内側ナットを外す → 外側へ抜く
リミットスイッチ | 配線と2本のM2を外す → 交換後に復帰高さを再調整
軸受・送りねじ | ガラスとキャリアを外し、送りねじ・蓋・軸受の順で分解
印刷部品 | 割れ、インサート空回り、取付板の当たり面を点検

分解前に配線ラベルを残す。再組立後は導通・手回し・端点をもう一度確認。

最終更新日：2026年9月15日

107

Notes: 交換・再調整のとき
分解前に配線ラベルを残す。再組立後は導通・手回し・端点をもう一度確認。
https://github.com/dainakai/plate-lift-control
https://www.pololu.com/product/3130/specs
https://www.pololu.com/docs/0J71/4.2
https://www.pololu.com/docs/0J71/4.14
https://www.fa.omron.co.jp/product/item/SS-01GL13-E/

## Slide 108

保守

箱の保守：天板と電源側板から開く

01

DC電源とUSBを外す。天板4本を外し、端子と配線を確認する。

電源側板も4本で外せる。配線の余長を使って静かに開く。

02

03

底板まで外す場合は、ベース固定のM3×12を2本外して箱を持ち上げる。

確認：底板の4本は箱の裏にある。駆動フレームは取り外す必要がない。

天板M3×8 ×4 ／ 電源側板M3×8 ×4

最終更新日：2026年9月15日

108

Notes: 箱の保守：天板と電源側板から開く
天板M3×8 ×4 ／ 電源側板M3×8 ×4
DC電源とUSBを外す。天板4本を外し、端子と配線を確認する。
電源側板も4本で外せる。配線の余長を使って静かに開く。
底板まで外す場合は、ベース固定のM3×12を2本外して箱を持ち上げる。
底板の4本は箱の裏にある。駆動フレームは取り外す必要がない。
https://github.com/dainakai/plate-lift-control
https://www.pololu.com/product/3130/specs
https://www.pololu.com/docs/0J71/4.2
https://www.pololu.com/docs/0J71/4.14
https://www.fa.omron.co.jp/product/item/SS-01GL13-E/

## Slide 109

3Dデータと検証

公開データの使い方と検証範囲

収録内容 | 使い方・検証範囲
印刷用STL・ZIP | 装置の印刷部品14個。各1個、mm単位・印刷姿勢
購入部材一覧 | 型番・装置1台の必要数・使う場所・購入先を確認
動作GIF | 購入部品を含むCADアセンブリの68 mm昇降イメージ
CADとSTL | 新しい箱とベースの形状・穴・取付と昇降域の干渉を確認
現物での確認 | 保持・配線の曲げ・発熱・脱調・印刷品質を実機で確認

GIFは実機映像ではない。動作確認済みの機構を使い、電子箱は6分割の設計を収録。

最終更新日：2026年9月15日

109

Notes: 公開データの使い方と検証範囲
GIFは実機映像ではない。動作確認済みの機構を使い、電子箱は6分割の設計を収録。
https://github.com/dainakai/plate-lift-control
https://www.pololu.com/product/3130/specs
https://www.pololu.com/docs/0J71/4.2
https://www.pololu.com/docs/0J71/4.14
https://www.fa.omron.co.jp/product/item/SS-01GL13-E/

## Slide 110

参照

参照する資料

資料 | 掲載先・内容
ソフトとダウンロード | github.com/dainakai/plate-lift-control
購入部材一覧 | hardware/bom.md：MISUMI型番・購入先・必要数
Pololu公式資料 | pololu.com/docs/0J71：Ticの接続・設定・操作
OMRON SS-01GL13-E | メーカー図面：端子・取付穴・レバー動作
図の寸法根拠 | メーカー図面と実測値。ねじ山・配線の曲げは一部省略

説明書の更新日と公開ファイルはGitHubのREADMEから確認できる。

最終更新日：2026年9月15日

110

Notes: 参照する資料
説明書の更新日と公開ファイルはGitHubのREADMEから確認できる。
https://github.com/dainakai/plate-lift-control
https://www.pololu.com/product/3130/specs
https://www.pololu.com/docs/0J71/4.2
https://www.pololu.com/docs/0J71/4.14
https://www.fa.omron.co.jp/product/item/SS-01GL13-E/

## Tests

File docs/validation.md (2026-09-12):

# 検証の範囲

## 0.2.0の確認

公開前にPython 3.11の独立した環境へ `uv.lock` に従ってインストールし、47件のテストとRuffの静的検査に通りました。
テストでは接続された装置にコマンドを送りません。

| 対象 | 確認内容 |
| --- | --- |
| Ticの状態読み取り | シリアル番号の先頭の0、稼働時間、電圧、リミット、異常一覧 |
| エラーなしの表示 | `None` を文字ごとの異常へ分割しない。実際の `Low VIN` などは残す |
| 移動 | 原点復帰、上下端の移動、通常終了で下端かつ無励磁 |
| 異常時 | 両リミットの作動、移動異常、期限超過、中断で位置記録を無効化 |
| 位置記録 | 別機体、再起動、ストローク変更、位置カウンター変更、不確かさの変更を検出 |
| 明示的な原点復帰 | `home` は保存済みの下端位置でも原点復帰を実行 |
| 初期値 | 68 mm、最大速度150000000。旧50 mmは明示的に選択可能 |
| 実験サンプル | USBなしの2往復、終了時の下端確認、移動異常後の自動復帰を抑止 |

GitHub ActionsはmacOS、Windows、Linuxでインストール、テスト、静的検査、サンプル実行、パッケージのビルドを行います。
各コミットの実行結果は [Actions](https://github.com/dainakai/plate-lift-control/actions/workflows/test.yml) で確認できます。
CIは実際のTic用ドライバーやUSB接続を検証しません。

## 実機の確認

装置がPololuの公式アプリで正しく動作することは、装置の使用者から2026年9月12日に報告されています。
公式アプリでの速度150000000、電源入力電流約0.27 Aという使用結果も、既定速度を決める際の参考にしています。
電流値はモーター各相の電流制限とは別です。

公開版のスクリプトでMacとWindowsの実機USB操作を完了したという検証結果は、まだありません。
実機での動作確認では、原点復帰、上下の向き、リミット位置、停止後の保持を確認します。

## 制約

- ソフトは上下端のスイッチとTicの位置カウンターを使います。物理的な絶対位置やガラスの保持力は測定しません。
- 手回しや無通電時のずれは検出できません。公式アプリや手回しで動かしたあとも `home` を行います。
- モーター停止後は無励磁にします。無通電で保持できる機構を前提としています。
- 2個のNCスイッチを前提としますが、個々の断線と実際のリミット作動を電気的に区別することはできません。
- 撮影サンプルのカメラ処理は表示のみです。実際に取得する処理へ置き換える必要があります。

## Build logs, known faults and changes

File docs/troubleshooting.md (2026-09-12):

# 困ったとき

| 症状 | 対応 |
| --- | --- |
| `uv` が見つからない | インストール後にターミナルまたはPowerShellを開き直します。 |
| `ticcmd` が見つからない | Pololuソフトをインストールし、ターミナルを開き直します。必要なら `--ticcmd` で場所を指定します。 |
| `pyproject.toml` が見つからない | ZIPを展開し、このファイルが入っているフォルダへ `cd` します。 |
| `uv sync --locked` が失敗する | まず通信エラーの有無を確認します。ファイルの組み合わせが違う場合はZIPを新しいフォルダへ展開し直します。 |
| 公式アプリでは動くがスクリプトから接続できない | 公式アプリを終了します。Windowsでは同時接続できません。 |
| `fault during homing: N; o; n; e` | 旧配布版の不具合です。このリポジトリから入れ直してください。エラーなしを示す `None` の誤判定は修正済みです。 |
| `Low VIN` | USBだけではモーターを動かせません。モーター用電源、主電源スイッチ、ヒューズ、Tic入力電圧を確認します。 |
| `both ... limits ... active` | NC線の抜け、SCL/SDAの割り当て、レバーの状態を確認します。 |
| 原点復帰がタイムアウトする | 主電源を切り、移動方向、ツメがレバーを押せるか、リミットの設定と配線を確認します。 |
| `another platectl process ... lock` | 実行中のコマンドまたは撮影サンプルが終わるまで待ちます。実行中にロックを消さないでください。 |
| 公式アプリや手回しで位置を変えた | 次に使う前に `home` で原点復帰をやり直します。手回しによる移動はソフトから検出できません。 |

詳しいTicの状態を読むには、公式アプリを閉じて次を実行します。

```text
ticcmd --status --full
uv run platectl status --json
```

[READMEへ戻る](../README.md)

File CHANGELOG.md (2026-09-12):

# 変更履歴

## 0.2.0

- 操作ソフトを独立した公開リポジトリとして配布。
- MacとWindows向けの導入手順、Tic設定、上下操作、撮影処理との連携をREADMEへ記載。
- R10/R11の68 mmストロークを既定値に変更。旧50 mmは `--travel-mm 50` で選択可能。
- 通常移動の速度をTic単位の150000000（約14.06 mm/s）に設定。
- `home` は保存位置にかかわらず下端の原点復帰をやり直す。
- 保存した停止位置を再利用するときに、Ticの位置カウンター、位置の不確かさ、停止状態も照合。
- タイムアウト表示に実際の期限を表示。
- 校正用の上昇と試料撮影用の下降を行うサンプルを追加。
- 撮影サンプルは模擬動作が既定値。実機は `--backend ticcmd` で明示的に選択。
- 実験用の終了ヘルパーは、移動異常や中断後に自動復帰しない。
- 旧配布物で発生した `None` を `N; o; n; e` と誤判定する不具合の修正を引き継ぎ。

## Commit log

2026-09-12 Publish plate lift control with macOS and Windows setup guide
2026-09-15 Publish assembly manual, hardware print set and motion GIF
    [bom.csv, ガラスホルダー前枠.stl, ガラスホルダー接続腕.stl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]
